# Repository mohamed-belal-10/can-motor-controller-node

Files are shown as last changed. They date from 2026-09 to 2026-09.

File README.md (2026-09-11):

# CAN-Connected Closed-Loop DC Motor Controller Node

A single PCB "smart joint" for robot arms, rovers, or any multi-actuator robotic
system: it bolts onto a DC gearmotor, closes a cascaded current → speed →
position control loop locally on an STM32, and takes setpoints over a shared
CAN bus instead of running dedicated wires back to a central controller.
Multiple nodes share one twisted-pair CAN bus, each addressed independently.

A portfolio project by **Mohamed Belal ("Belo")** — Mechatronics Engineering,
GUC.

---

## Why this project

- **First board with a real power stage.** Current in the amps range, not the
  milliamps of a typical digital-signal board — Kelvin sensing considerations,
  thermal copper, and return-path separation under switching noise.
- **Introduces CAN bus** as a communication protocol, end to end: transceiver
  hardware, bxCAN peripheral configuration, bit-timing, and a companion
  USB-CAN adapter to test it from a laptop.
- **Introduces cascaded multi-loop control** (current → speed → position),
  the conceptual step up from a single-loop PID.
- Built from and cross-checked against two open reference designs: CVRA's
  `motor-control-board` (KiCad, CC-BY) and Cormack's STM32L433 motor driver.

---

## System overview

```
                    ┌──────────────┐      ┌──────────────┐
   12V IN  ────────▶│ LM2596S-5V   │─5V──▶│ AMS1117-3.3  │────▶ 3.3V rail
   (motor            │ buck (switch)│      │ LDO (linear) │      │
    supply)          └──────────────┘      └──────────────┘      │
        │                                                          │
        │ (direct, unregulated)                                    │
        ▼                                                          ▼
   ┌──────────┐    PWM x2      ┌──────────┐   IPROPI    ┌─────────────┐
   │ DRV8874  │◀───────────────│ STM32F103│◀────────────│ (internal to │
   │ H-bridge │                │  C8T6    │             │  DRV8874)    │
   └────┬─────┘                └────┬─────┘             └─────────────┘
        │ motor terminals            │  I²C
        ▼                            ▼
   ┌──────────┐                ┌──────────┐        ┌──────────────┐
   │ DC MOTOR │────coupled────▶│  AS5600  │        │ SN65HVD230   │◀──▶ CAN H/L
   │          │  (shaft end)   │ (angle)  │        │ (transceiver)│    to bus
   └──────────┘                └──────────┘        └──────────────┘
```

Two boards are designed here:

| Board | Role | Location |
|---|---|---|
| **`motor_controller`** | Main node — MCU, power stage, H-bridge, CAN interface | [`hardware/motor_controller/`](hardware/motor_controller/) |
| **`AS5600_Encoder_Node`** | Small sub-PCB carrying the bare AS5600 angle sensor, linked to the main board over a 4-pin JST-SH cable | [`hardware/AS5600_Encoder_Node/`](hardware/AS5600_Encoder_Node/) |

The AS5600 lives on its own tiny PCB — not a generic breakout module —
specifically so the main board's own calculated I²C pull-up resistors are
the *only* pull-ups on the bus (most off-the-shelf breakout modules bundle
their own, which would silently change the bus's effective pull-up value).

---

## Gallery

### Main board — `motor_controller`

<table>
<tr>
<td width="50%">

**PCB layout** (KiCad, top copper + silkscreen)

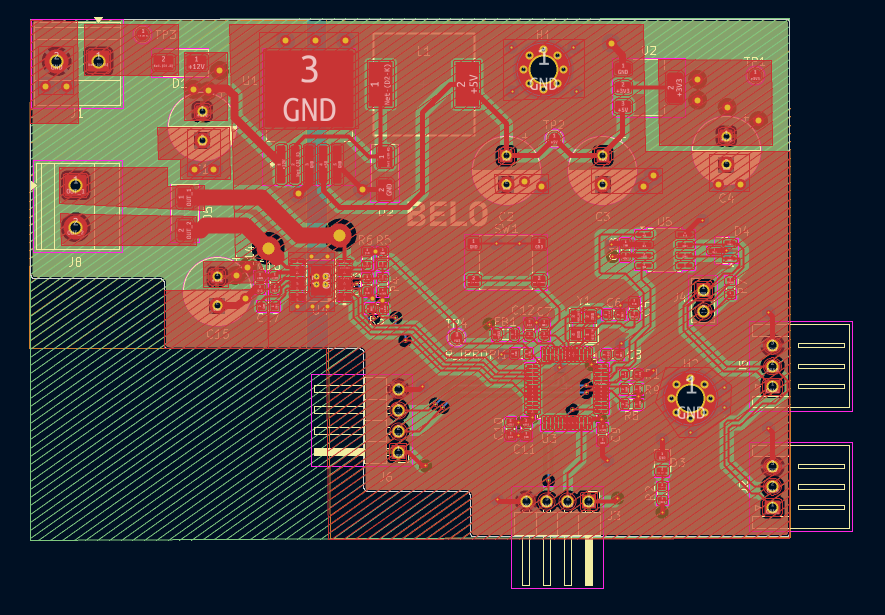
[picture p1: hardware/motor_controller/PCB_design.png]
motor_controller PCB layout


</td>
<td width="50%">

**3D render**

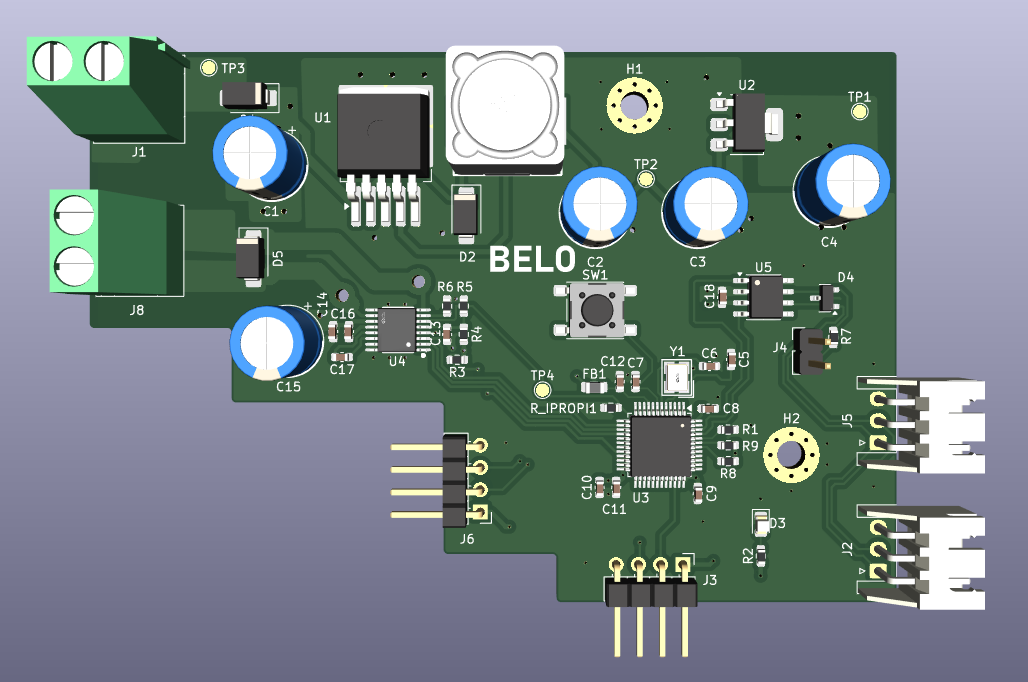
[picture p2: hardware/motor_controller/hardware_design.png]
motor_controller 3D render


</td>
</tr>
</table>

### Sub-board — `AS5600_Encoder_Node`

<table>
<tr>
<td width="50%">

**PCB layout**

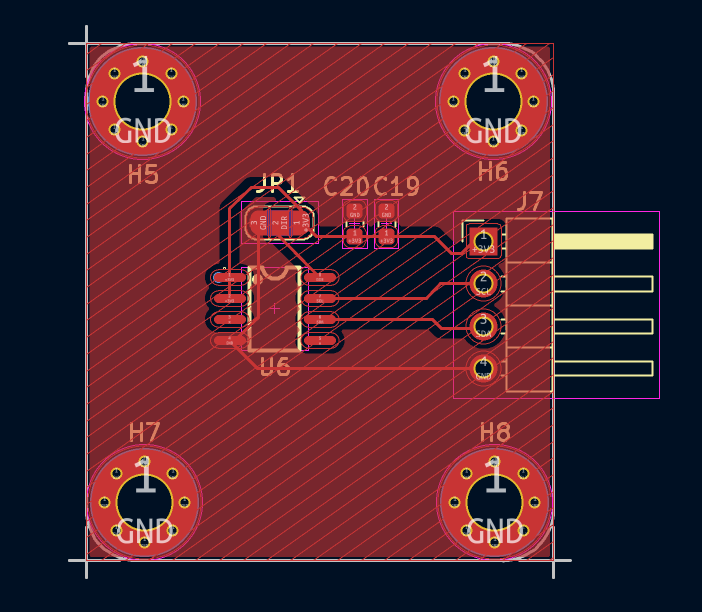
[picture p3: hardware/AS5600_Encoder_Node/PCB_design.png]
AS5600_Encoder_Node PCB layout


</td>
<td width="50%">

**3D render**

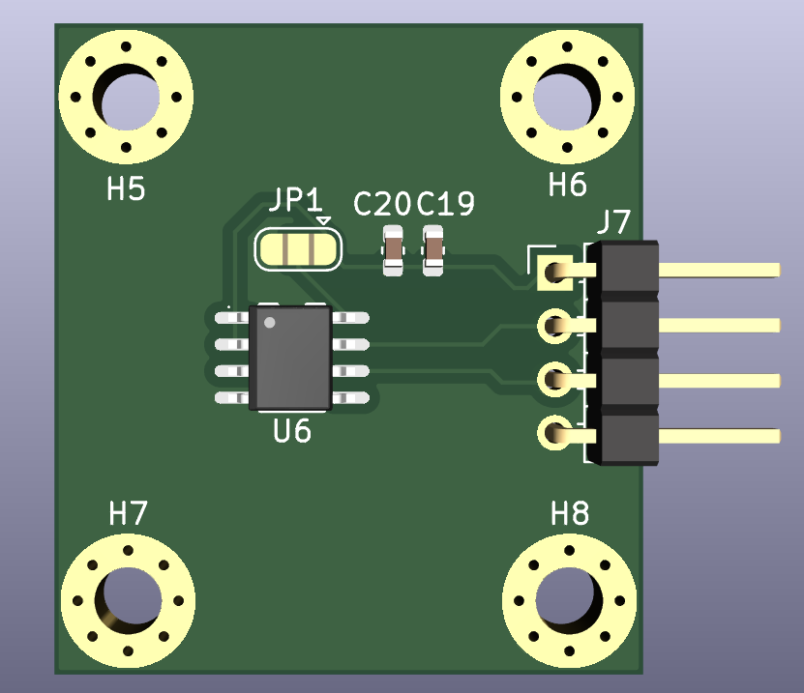
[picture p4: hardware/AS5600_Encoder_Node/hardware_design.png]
AS5600_Encoder_Node 3D render


</td>
</tr>
</table>

---

## Repository structure

```
.
├── README.md
├── LICENSE
├── docs/                                       Design documentation
│   ├── CAN_Motor_Controller_Node_Spec.md           Full BOM, design decisions, CAN protocol, pin map
│   └── CAN_Motor_Controller_Node_PCB_Layout_Guidelines.md   Placement, routing, plane strategy, DRC targets
└── hardware/
    ├── motor_controller/                       Main CAN motor controller node
    │   ├── motor_controller.kicad_pro/.kicad_sch/.kicad_pcb/.kicad_prl
    │   ├── PCB_design.png                          PCB layout screenshot
    │   ├── hardware_design.png                     3D render
    │   └── manufacturing/
    │       ├── gerbers/                            Gerber + drill files
    │       └── motor_controller-gerbers.zip         Fab-ready zip (JLCPCB format)
    └── AS5600_Encoder_Node/                    AS5600 magnetic encoder sub-PCB
        ├── AS5600_Encoder_Node.kicad_pro/.kicad_sch/.kicad_pcb/.kicad_prl
        ├── PCB_design.png                          PCB layout screenshot
        ├── hardware_design.png                     3D render
        └── manufacturing/
            ├── gerbers/
            └── AS5600_Encoder_Node-gerbers.zip
```

All KiCad projects are **KiCad 8+** format.

---

## Main board — `motor_controller`

### Core components

| Subsystem | Part | Notes |
|---|---|---|
| MCU | STM32F103C8T6 (LQFP-48) | 72 MHz, bxCAN, runs all 3 PID loops + CAN stack |
| Clock | 8 MHz HSE crystal, C_L = 20 pF | Required for reliable 500 kbps CAN bit timing (HSI is too loose) |
| Motor driver | DRV8874 (HTSSOP-16, PowerPAD) | Integrated current sense (IPROPI) and cycle-by-cycle current chopping — no external shunt/amplifier needed |
| Power stage | LM2596S-5V (buck) → AMS1117-3.3 (LDO) | Two-stage: switching for efficiency, then linear to give the current-sense ADC a clean reference |
| CAN transceiver | SN65HVD230 (SOIC-8) | 3.3V-only, high-speed mode, `NUP2105L` TVS array for bus ESD protection |
| Encoder | AS5600 (on its own sub-PCB) | 12-bit absolute angle over I²C — see below |
| Actuator | JGA25-370, 12V, 133 RPM, 20 kg·cm | Brushed DC gearmotor, 1:78 gearbox |

### Electrical specs

- **Motor supply:** 12 V nominal (6–18 V DRV8874 range)
- **Current limit:** 2.0 A hardware trip (`I_TRIP`, VREF divider-set), cycle-by-cycle chopping
- **PWM switching frequency:** 20 kHz (H-bridge), 150 kHz (buck)
- **Stackup:** 4-layer — L1 signal, L2 solid GND, L3 split power (VM/3.3V), L4 signal
- **CAN bus:** 500 kbps, standard 11-bit IDs, JST-XH 3-pos daisy-chain connectors (IN/OUT), jumper-selectable 120 Ω termination

### CAN protocol

| Frame | Direction | ID | Payload |
|---|---|---|---|
| Command | host → node | `0x100 + node_id` | `float32` setpoint, `uint8` mode (0=position, 1=speed, 2=current) |
| Telemetry | node → host | `0x200 + node_id` | `float32` position, `uint16` current (mA), `uint8` fault flags |

`node_id` is assigned in firmware at flash time — no address jumpers on the
board.

### Design status

- ✅ All five schematic sheets complete (Power Stage, MCU Core, Motor Drive,
  CAN Bus, Sensing), ERC clean.
- ✅ Every component value and part number closed, across four audit passes
  (full history in [`docs/CAN_Motor_Controller_Node_Spec.md`](docs/CAN_Motor_Controller_Node_Spec.md)).
- ✅ Layout complete; gerbers generated (see `manufacturing/`).
- ⚠️ **Flagged, unresolved:** DRV8874 power-up sequencing (VCC vs. VM order)
  not verified against the datasheet.
- ⚠️ **Open before re-ordering:** cross-check the main board's AS5600 link
  connector pin order against the sub-PCB's `J1`/`J7` connector — both
  footprints were placed independently.
- 🚚 **Externally sourced, not yet in hand:** DRV8874 (not stocked locally —
  ordered internationally), diametrically-magnetized magnet (must confirm
  magnetization type with seller before buying).

---

## Sub-board — `AS5600_Encoder_Node`

A minimal breakout for the bare AS5600 magnetic rotary position sensor
(SOP-8), designed specifically to avoid the double-pull-up problem that
off-the-shelf AS5600 modules introduce.

| Item | Detail |
|---|---|
| Sensor | AS5600 (SOP-8), 12-bit absolute angle over I²C |
| Power wiring | `VDD5V` and `VDD3V3` tied together, fed from the main board's 3.3V rail (required for correct 3.3V single-supply operation per datasheet) |
| Decoupling | 100 nF + 10 µF in parallel across the tied VDD node → GND (matches datasheet Fig. 13, 3.3V-mode) |
| Direction select | 3-pad solder jumper (`DIR`: GND = CW-increasing, VDD = CCW-increasing) — bridged at assembly time once motor orientation is known |
| Link to main board | JST-SH, 1.0 mm pitch, 4-position — carries `+3V3`, `SCL`, `SDA`, `GND` |
| Mounting | Glued flat to the motor's rear shaft-stub end face, read through a 1.0–1.5 mm air gap by a 6 mm diametric NdFeB magnet |
| Encoder resolution | 4096 counts/rev at the motor shaft → 319,488 counts/rev at the JGA25-370's output shaft (through its 1:78 gearbox) |

The AS5600 mounting bracket (clamp-style, sized to the motor's 25 mm body OD)
is specified mechanically in [`docs/CAN_Motor_Controller_Node_Spec.md`](docs/CAN_Motor_Controller_Node_Spec.md#9-as5600-mounting-bracket-mechanical-spec--solidworks-task)
but deliberately not finalized until the physical sub-PCB and motor are in
hand to confirm dimensions.

---

## Documentation

| Document | Covers |
|---|---|
| [`docs/CAN_Motor_Controller_Node_Spec.md`](docs/CAN_Motor_Controller_Node_Spec.md) | Full BOM with sourcing/pricing notes, design-decision rationale, CAN protocol definition, STM32 pin assignment tracker, CAN-adapter companion tool, AS5600 mounting bracket spec |
| [`docs/CAN_Motor_Controller_Node_PCB_Layout_Guidelines.md`](docs/CAN_Motor_Controller_Node_PCB_Layout_Guidelines.md) | Trace sizing, via strategy, floorplan, placement rules, ground/power plane strategy, CAN routing, thermal, DRC targets, pre-routing checklist |

---

## Build sequence

1. Schematic capture (CAN node + power stage + DRV8874 + AS5600) — **done**
2. ERC clean — **done**
3. Layout — **done**
4. DRC clean, JLCPCB stackup check, order
5. Bring-up: power rails → CAN enumeration → AS5600 sanity read → close current loop → speed loop → position loop
6. Bring up the companion CAN-USB adapter and drive the node from a laptop with real command/telemetry frames

Full detail on each step, including the CAN-USB adapter's own BOM, wiring,
and firmware plan, is in [`docs/CAN_Motor_Controller_Node_Spec.md`](docs/CAN_Motor_Controller_Node_Spec.md#7-build-sequence).

---

## Fabrication

Both boards are designed for JLCPCB (4-layer main board, 2-layer sub-PCB).
Ready-to-upload gerber/drill packages are checked in under each board's
`manufacturing/` folder. Re-export from KiCad's Plot dialog after any layout
change rather than editing the checked-in gerbers by hand.

## Reference designs

- [CVRA `motor-control-board`](https://github.com/cvra) — KiCad, CC-BY, near-identical spec; source for the CAN daisy-chain connector and termination-jumper approach.
- Cormack's STM32L433 motor driver — single-board layout reasoning, undervoltage-lockout-as-safety-feature technique.

## License

MIT — see [`LICENSE`](LICENSE).

This repository contains PCB hardware design files (KiCad schematics,
layouts, and manufacturing outputs) alongside documentation. The MIT License
is applied for simplicity and consistency with the author's other portfolio
repositories; no warranty is made or implied about the fitness of any
hardware design herein for use with live mains, high-current, or
safety-critical applications. Build and operate at your own risk.

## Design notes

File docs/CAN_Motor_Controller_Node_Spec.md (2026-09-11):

# CAN-Connected Closed-Loop DC Motor Controller Node

**A portfolio project for Mohamed Belal ("Belo") — Mechatronics Engineering, GUC**
**Status:** **Every electrical design decision and component value closed**, across four audit passes. **Schematic capture in progress in KiCad — all five subsystem sheets drawn (Power Stage, MCU Core, Motor Drive, CAN Bus, Sensing).** **One item flagged but deliberately unresolved:** DRV8874 power-up sequencing (VCC vs. VM order) — check during schematic capture. **Three items remain deliberately deferred:** DRV8874 sourcing, magnet sourcing (both external, your action), and the AS5600 bracket finalization (§9, paused until the sub-PCB layout exists). **One item open before ERC/layout:** cross-check that the main board's AS5600 link connector and the sub-PCB's `J1` connector share the same pin order (§3.4) — both were placed independently.
**Prerequisite:** ESP-Drone board ordered and fabricated first

---

## 1. Project Description

This is a single PCB — one "smart joint" of the kind used in robot arms, rovers, or any multi-actuator robotic system. It bolts onto a DC motor, closes a cascaded position/speed/current control loop locally, and takes setpoints over a CAN bus instead of running dedicated wires back to a central controller. Two or more of these boards can share one twisted-pair CAN bus, each addressed independently.

**What it does, end to end:**
1. A command arrives over CAN — *"go to position X"* or *"hold speed Y."*
2. The onboard STM32 runs three nested PID loops (current → speed → position) to get the motor there safely and smoothly.
3. The board reports back over CAN: current position, speed, motor current, fault flags.

**Why this project, specifically:**
- It's the first board with a **real power stage** — current in the amps range, not the milliamps of ESP-Drone's digital signals. This is the actual PCB skill gap in your record: Kelvin sensing, thermal copper, return-path separation under switching noise.
- It introduces **CAN bus**, currently a zero on your skill matrix and the exact protocol your DLR-thesis framing is built around.
- It introduces **cascaded multi-loop control**, the conceptual bridge between the single-loop PID you already proved on maglev and the state-space work further down your priority list.
- It's a legitimate, honest answer to "tell me about your robotics work" — an actuator control node, not an inflated claim.

**Reference designs this is built from:** CVRA's `motor-control-board` (KiCad, CC-BY, near-identical spec) and Cormack's STM32L433 motor driver (single-board layout reasoning, undervoltage-lockout-as-safety-feature trick). Read both `.kicad_pcb` files directly before drawing your own schematic, the way you did with ESP-Drone.

---

## 2. System Architecture

```
                    ┌──────────────┐      ┌──────────────┐
   12V IN  ────────▶│ LM2596S-5V   │─5V──▶│ AMS1117-3.3  │────▶ 3.3V rail
   (motor            │ buck (switch)│      │ LDO (linear) │      │
    supply)          └──────────────┘      └──────────────┘      │
        │                                                          │
        │ (direct, unregulated)                                    │
        ▼                                                          ▼
   ┌──────────┐    PWM x2      ┌──────────┐   IPROPI    ┌─────────────┐
   │ DRV8874  │◀───────────────│ STM32F103│◀────────────│ (internal to │
   │ H-bridge │                │  C8T6    │             │  DRV8874)    │
   └────┬─────┘                └────┬─────┘             └─────────────┘
        │ motor terminals            │  I²C
        ▼                            ▼
   ┌──────────┐                ┌──────────┐        ┌──────────────┐
   │ DC MOTOR │────coupled────▶│  AS5600  │        │ SN65HVD230   │◀──▶ CAN H/L
   │          │  (shaft end)   │ (angle)  │        │ (transceiver)│    to bus
   └──────────┘                └──────────┘        └──────────────┘
```

---

## 3. Final Component List

### 3.1 Core compute & communication

| Component | Role | Key specs | Package | Local availability |
|---|---|---|---|---|
| **STM32F103C8T6** | Main MCU. Runs all three PID loops, reads the encoder over I²C, drives PWM to the H-bridge, runs the CAN peripheral (bxCAN). | 72 MHz, bxCAN built in, 5V-tolerant GPIO on most pins | LQFP-48 | ✅ Local (Future Electronics Egypt / UGE) |
| **8MHz crystal (HSE) + load caps** | External oscillator for the STM32 — feeds the internal PLL to reach the full 72MHz core clock. **Required for reliable CAN bit timing** at 500kbps; the internal RC oscillator (HSI) has looser tolerance and drift that isn't recommended for CAN. This is genuinely new territory for this board — previous boards (maglev) used the Blue Pill module, which has this circuit built in; this board uses the bare LQFP-48 chip, so the oscillator circuit has to be designed here for the first time. **Sourced: 3225 SMD quartz 4-pin crystal, 8MHz, `C_L=20pF` (UGE Electronics Egypt).** Load caps: **C1=C2=20pF**, matched directly to the crystal's own specified load capacitance. No external feedback resistor needed — internal to the STM32. Connects to the dedicated `OSC_IN`/`OSC_OUT` pins, not the general GPIO pool. | 8MHz, C_L=20pF, ±10ppm tolerance | 3225-SMD (crystal) + 0402/0603 (caps) | ✅ Local (UGE Electronics Egypt) |
| **Reset circuit (`NRST`)** | Manual/clean reset for the STM32. **No external pull-up needed** — the chip has one built in (~40kΩ, per datasheet). Add a **100nF capacitor** `NRST`→GND to filter noise and stretch the reset pulse on power-up, plus a **momentary push-button** `NRST`→GND for manual reset during bring-up/debugging without power-cycling the board. | 100nF cap + momentary pushbutton | Passive + button | ✅ Local, trivially common parts |
| **`BOOT0` strapping** | Selects boot source: low=main flash, high=system bootloader. **Tied to GND via a fixed 10kΩ pull-down** — no jumper. Since programming is exclusively via ST-Link/SWD (same as ESP-Drone and maglev), the system bootloader is never needed, so a fixed tie-down is simpler and more reliable than a selectable jumper. | 10 kΩ | Passive, 0603/0805 | ✅ Local |
| **STM32 decoupling capacitors** | Standard MCU support that was missing from the BOM entirely. **Precise breakdown for this LQFP-48 package: 3 digital `VDD` pins → 3× 100nF ceramic (one per pin, placed as close to each pin as layout allows), plus 1× 4.7µF bulk cap on the `VDD` rail. Separately, `VDDA`/`VSSA` (the analog supply feeding the ADC) gets its own 100nF, ideally isolated from digital `VDD` by a small series ferrite bead.** `VBAT` ties directly to `VDD` (no RTC backup battery in this design). This isn't a generic nice-to-have on this board specifically: `VDDA` is the literal reference voltage the ADC measures `IPROPI` against, so noise leaking onto it from the digital rail *is* current-measurement error, not just abstract EMC hygiene — it connects directly to the entire reason this board has a two-stage `LM2596→AMS1117` power architecture in the first place. All of these caps benefit from via-ing straight down to the solid ground plane (L2 of the 4-layer stackup already decided) right under each pad. | 3× 100nF (digital VDD) + 1× 4.7µF bulk + 1× 100nF (VDDA) + ferrite bead | Passive | ✅ Local |
| **Power-on LED + resistor** | Genuinely missing until this audit: no visual "is this board alive" indicator existed anywhere. Placed on the 3.3V rail — the first, cheapest signal you get the moment power is applied, before any probe or debugger is connected. Standard practice, especially valuable across the multi-stage bring-up sequence in §7. | Standard LED + series resistor sized for ~2-5mA at 3.3V (e.g. 1kΩ for a typical red LED) | Passive + LED | ✅ Local |
| **SN65HVD230** | CAN transceiver. Converts the MCU's digital CAN TX/RX signals into the differential CAN-H/CAN-L signaling that travels on the bus, and back. Standard **100nF local decoupling cap** at the VCC pin (not previously listed). **`RS` (pin 8) tied directly to GND** — selects high-speed mode (datasheet: strong pull-down to GND = high-speed, no slew-rate limiting). Standby/sleep mode is never used on this board, so a fixed tie-down is correct rather than routing RS to a GPIO. **`Vref` (pin 5) left floating (N/C)** — only meaningful with split termination (tying to the split's center point); this board uses standard single-resistor termination, and the datasheet explicitly permits leaving Vref floating when unused. | **3.3V supply only** — do not power from 5V | SOIC-8 | ✅ Local (UGE Electronics Egypt) |
| **120 Ω termination resistor** | Placed across CAN-H/CAN-L at each physical end of the bus cable, jumper-selectable. Prevents signal reflections that corrupt CAN frames. **Decided: 2-pin, 2.54mm pin header + removable jumper shunt cap**, in series with the resistor. Cap installed = termination enabled; cap removed = disabled. Chosen over a solder jumper specifically because the board's dual JST-XH IN/OUT connectors are designed for future daisy-chaining — if a third node is ever added mid-chain, this board's termination may need to be toggled off without breaking out a soldering iron. Matches how CVRA's reference board (this project's basis) handles it. | Standard 0805/1206 resistor + 2-pin 2.54mm header + shunt cap | Passive | ✅ Local (generic passive, any store) |

### 3.2 Power stage & motor drive

| Component | Role | Key specs | Package | Local availability |
|---|---|---|---|---|
| **DRV8874** | H-bridge motor driver. Takes PWM logic signals from the MCU and switches full motor current (volts/amps) to the motor. **Has a built-in current-sense pin (IPROPI)** — outputs a current proportional to actual motor current, set by one external resistor (`R_IPROPI`). No separate shunt resistor or current-sense amplifier IC needed. **Two layout requirements not previously noted:** standard **100nF local decoupling** at the `VCC` (logic supply) pin; and the HTSSOP-16 package's **exposed thermal pad needs via-stitching to a copper pour** for heat dissipation, genuinely relevant here given the current-limiting events this board is designed to handle regularly (`I_TRIP` chopping during stalls). | Up to ~6.5 A continuous, 4.5–37 V motor supply, integrated current sense, integrated current regulation/chopping | HTSSOP-16 (PowerPAD) | ❌ **Not stocked locally.** You've confirmed you'll source it internationally regardless (Digikey/Mouser/RS/TME, or a Pololu carrier board as an import fallback). Lead time and shipping cost apply — order early. |
| **R_IPROPI** | Sets the current-sense gain (converts DRV8874's IPROPI output current into a readable voltage for the ADC). **Calculated: 2.2 kΩ** — sized so the STM32's 3.3V ADC reads full-scale at ~3.3A (headroom above the JGA25-370's 1.2A stall current), giving stall current a clean ~36% of ADC range. `A_IPROPI` = 455 µA/A per DRV8874 datasheet. Output routes to **`PA0` (ADC1_IN0)** — see §5.2 pin tracker. | 2.2 kΩ, precision resistor recommended (1% tolerance) | Passive, 0603/0805 | ✅ Local |
| **VREF divider** | Sets the DRV8874's hardware current-chopping trip point (`I_TRIP`), independent of firmware — a physical safety backstop. **Calculated: R1 = 3.3 kΩ (3.3V→node), R2 = 5.1 kΩ (node→GND)**, giving `VREF = 2.004V` → `I_TRIP ≈ 2.0A`. Add a **100nF filter cap** from the VREF node to ground — the divider alone will pick up H-bridge switching noise, and since VREF sets a hard trip threshold, that noise can cause false trips. | R1 = 3.3kΩ, R2 = 5.1kΩ, C = 100nF | Passive | ✅ Local |
| **LM2596S-5V** | Buck converter, bare IC, fixed 5V output. Steps 12V motor supply down to a regulated 5V intermediate rail. **This is your one real switching-regulator layout exercise** — inductor selection, switching-node layout, feedback network — with no output-voltage calculation needed since it's a fixed-voltage part. | 3A continuous, 150 kHz switching, TO-263 | TO-263 (SMD) | ✅ Local (UGE Electronics Egypt) |
| **AMS1117-3.3** | Linear regulator (LDO), fixed 3.3V output. Takes the 5V rail down to the clean 3.3V logic rail powering the STM32, SN65HVD230, and AS5600. Chosen specifically to sit *after* the switcher: an LDO rejects the switching noise the LM2596 leaves on its output, giving the MCU's ADC a cleaner reference — which matters because the ADC is also reading the DRV8874's IPROPI current-sense signal. Noise on the supply becomes noise in the current measurement. **Output cap: 22µF electrolytic, 25V rating** — confirmed sourced (Flux Electronix Egypt, 0.75 EGP). Electrolytic works as well as tantalum here: its higher ESR naturally sits within the AMS1117's required 0.3–22Ω stability window, the opposite problem ceramic has. **Note: through-hole part** — since the board's assembly plan is JLCPCB SMT, this one component will likely need hand-soldering after assembly rather than going through the automated run, unless swapped for an SMD electrolytic. **Input cap: 10µF tantalum/electrolytic.** | 1A output, dropout ~1.1V, fixed 3.3V | SOT-223 | ✅ Local / near-universal — stocked everywhere, including as a standalone part at UGE |
| **Inductor** (buck stage) | Energy-storage element for the switching regulator. | **68 µH — confirmed part: `CD54-680M` (DMBJ / Dongguan Zhenbaojia Electronics), 6.1×5.5×4.85mm, in stock at 11.50 EGP. Datasheet-confirmed: DCR max 0.46Ω, IDC max 0.61A** (defined as the current causing either 25% inductance drop or 40°C temperature rise, whichever is smaller — a thermally-soft limit, not a hard cliff edge). Checked against this rail's realistic load: STM32 (~35–50mA active) + SN65HVD230 (~10–70mA) + AS5600 (a few mA) totals roughly 100–150mA steady-state, giving **~4–6× headroom** under the 0.61A rating — comfortable margin including power-up inrush. DCR loss at this current is trivial (~10mW). **No further verification needed — this is a fully specified, sourced, in-stock part.** | SMD power inductor | ✅ Local, confirmed in stock, datasheet-verified |
| **Schottky catch diode** (buck stage) | Provides the current path when the LM2596's internal switch is off. | 3A, low forward-voltage Schottky (e.g. SS34-class) | SMA/DO-214 | ✅ Local (generic, widely stocked) |
| **Reverse-polarity protection diode** | Series diode in the +12V input line, before it splits to DRV8874 `VM` and the `LM2596S-5V` input. Blocks all current if the supply is ever connected backward — a real bench mistake this protects against, cheaply. **Reuses the same 3A SS34-class Schottky already specified for the buck stage's catch diode** — one fewer distinct BOM part rather than sourcing a second diode type. Forward drop (~0.4V) is inconsequential here: the motor tolerates 6–18V and the buck stage has ample input headroom either way. Power dissipation at `I_TRIP` (2A): ~0.8W momentarily during a stall — well within the diode's 3A rating with real margin. A P-channel MOSFET "ideal diode" would lose less voltage/power, but adds gate-biasing complexity not worth it at these current levels for a first board. | Same part as buck catch diode — 3A SS34-class Schottky | SMA/DO-214 | ✅ Local (same sourcing as buck diode) |
| **`nFAULT` pull-up resistor** | Required for the DRV8874's open-drain `nFAULT` output to read as a valid logic high when no fault is present. | 10 kΩ | Passive, 0603/0805 | ✅ Local |
| **VM bulk capacitor + local decoupling** | Absorbs energy kicked back from the motor winding's inductance during switching/current-limit events, preventing voltage sag/spikes on the 12V rail that would otherwise show up as noise in the current-sense reading. **Sized via energy estimate: `E=½LI²` at I_TRIP=2.0A with an assumed ~2mH motor winding inductance (not datasheet-confirmed — this motor doesn't publish it) gives ~264µF for a 10% rail-voltage-rise tolerance.** Rounded to a standard value: **220–330µF electrolytic, 25V rated**, placed close to the DRV8874's VM pin, plus a **0.1–1µF ceramic** alongside it for the fast edges the electrolytic can't respond to in time. | 220–330µF/25V electrolytic + 0.1–1µF ceramic | Mixed | ✅ Local (basic, common values — same store tier as the AMS1117 cap) |
| **Bulk/decoupling capacitors** | Input/output filtering for the buck stage, input/output caps for the LDO (per AMS1117 datasheet — it needs a minimum output cap for stability), plus local decoupling at every IC's supply pin. | Electrolytic (bulk) + ceramic (decoupling), values per datasheet | Mixed | ✅ Local |

### 3.3 Sensing

| Component | Role | Key specs | Package | Local availability |
|---|---|---|---|---|
| **AS5600** | Magnetic rotary position sensor. Reads a small diametric magnet mounted on the motor shaft end and reports absolute shaft angle over I²C. Chosen over a mechanical 600 PPR encoder because it's **absolute** (always knows true position immediately, even after a reset or glitch) rather than incremental (loses position on any missed pulse or power interruption). **Implementation decided: bare SOP-8 IC on its own small dedicated sub-PCB (not a generic breakout module).** Most off-the-shelf breakout modules include their own onboard I²C pull-ups — combined with the main board's already-calculated 4.7kΩ pull-ups, the parallel result (~2.35kΩ) would quietly undo that calculation. Bare IC + own sub-PCB keeps the main board's pull-ups as the only ones on the bus, and matches how CVRA/Cormack's reference boards do it. Connects to the main board via a **JST-SH 1.0mm 4-position connector** (see §3.4 for the part) rather than a vague loose cable. Consider panelizing this small sub-PCB alongside the main board in the same JLCPCB order. **Power pin wiring — real datasheet requirement, previously missed: for 3.3V single-supply operation (this board's case), `VDD5V` and `VDD3V3` pins must be tied together and both fed from the 3.3V rail directly.** Getting this wrong (leaving `VDD3V3` floating, or not tying the two pins) is a real, easy schematic mistake for this specific chip. **Decoupling — corrected during schematic capture: `C1 = 100nF` + `C2 = 10µF`, both in parallel across the tied `VDD5V`/`VDD3V3` node to `GND`.** This matches the datasheet's own 3.3V-operation diagram (Fig. 13) exactly, not the separate 5V-mode "1µF LDO cap" table (Fig. 39) that doesn't apply once the internal LDO is bypassed by tying the two supply pins together. The 10µF value is specifically required for OTP burn procedures at 3.3V — kept in the design even though OTP burning isn't planned, since it's a negligible cost to leave in and guarantees the option stays open. **Bare IC confirmed local at UGE Electronics Egypt — but listed at 7,700 EGP, dramatically higher than typical pricing for this chip (a few dollars via LCSC).** Worth confirming actual unit quantity/price directly with UGE before ordering — this may be a bulk-reel listing or pricing error rather than a genuine per-unit cost. Your established LCSC + `easyeda2kicad` pipeline is very likely the cheaper route for this specific part even with international shipping. | 12-bit (4096 counts/rev), I²C interface, 3.3–5V supply | SOP-8 (bare IC, on its own sub-PCB) | ⚠️ Confirmed local but price unverified — compare against LCSC before committing |
| **Diametric magnet** | Mounted flush on the motor shaft end, read by the AS5600 through the PCB. **Mounting method decided: glued flat onto the shaft stub's end face**, centered on the rotation axis — not fitted around the shaft diameter via a collar. This sidesteps a real gap: the JGA25-370's rear shaft stub dimensions aren't published anywhere (checked the manufacturer manual and multiple listings — only the front output shaft is dimensioned). Gluing flat only requires the shaft end to be reasonably flat and accessible, true for essentially any small DC motor, and doesn't depend on knowing the shaft diameter at all. | 6mm diameter × 2.5mm–3mm thick, diametrically magnetized, N35–N42 grade | — | ❌ **Not confirmed local.** A cheap local candidate (Electra Store-style CNC/3D-printer supplier, 6×3mm, 8 EGP) was found, but the listing only says "neodymium disc magnet" — doesn't state diametric vs. axial magnetization, and the product photo shows the magnets stacking flat-face-to-flat-face, the classic behavior of **axial** magnets (poles on the flat faces). Diametric magnets (poles split across the round edge) don't stack that way. Axial magnets will not work with the AS5600 — they don't produce the rotating field the sensor needs. **Must confirm "diametrically magnetized" explicitly with the seller before buying**, or default to a specialty supplier / AliExpress listing that states it outright. |
| **I²C pull-up resistors** | Required on SDA/SCL lines for any I²C bus to function — open-drain signaling needs external pull-ups. **Calculated: 4.7kΩ, confirmed against the I²C-bus spec formula, not just assumed.** With `V_DD=3.3V`, `I_OL(max)=3mA`: `Rp(min) = (3.3−0.4)/0.003 ≈ 966Ω`. With an estimated bus capacitance of ~50pF (short on-board trace, two devices) at Standard-mode 100kHz (plenty fast — the AS5600 is only read once per ~10ms position-loop tick): `Rp(max) = 1000ns/(0.8473×50pF) ≈ 23.6kΩ`. **4.7kΩ sits comfortably mid-range** between 966Ω and 23.6kΩ — well-margined on both rise time and static current, not just a default that happens to work. Both resistors pull to **3.3V** (matching AS5600/STM32 logic level, not 5V). Placed only on the main board — deliberately **not** duplicated on the AS5600 sub-PCB, to avoid a second parallel pull-up quietly shifting the calculated value. | 4.7 kΩ ×2 | Passive | ✅ Local |
| **`JP1` — DIR configuration jumper** | Sets the AS5600's counting direction (`DIR` pin: GND = clockwise-increasing, VDD = counterclockwise-increasing). **Decided during schematic capture: 3-pad SMD solder jumper**, not a fixed tie. Center pad → `DIR`, one outer pad → `+3V3`, other outer pad → `GND`. Defers the CW/CCW decision from schematic time to assembly time — bridge whichever side matches the physical mounting once the motor and bracket are in hand, rather than guessing polarity now and risking a respin. | 3-pad solder jumper | Passive | ✅ Local (generic) |
| **AS5600 `OUT`/`PGO` pins** | **`OUT` (Pin 3): No-Connect.** Angle is read digitally over I²C (`ANGLE` register); the analog/PWM output isn't used. **`PGO` (Pin 5): No-Connect**, relying on its internal pull-up. Programming is done via I²C (datasheet Option A), so the OUT-pin programming path (Option B, which requires `PGO` tied to GND) doesn't apply. | — | — | — |

### 3.4 Connectors

| Component | Role |
|---|---|
| **SWD header (4-pin)** | Programming/debugging the STM32 via ST-Link. |
| **Power input connector** | Brings in 12V (or your chosen motor supply voltage). **Decided: 2-pin, 5.08mm pitch screw terminal block** (UGE Electronics Egypt or Micro Ohm's pluggable M+F version, ~6 EGP). Rated 10–16A depending on exact manufacturer — real-world worst-case current here is ~2.1–2.2A (motor's I_TRIP-limited draw plus buck stage overhead), giving **~5–7× headroom**, not a tight fit. Same part reused for the motor output connector below — one fewer distinct BOM entry. |
| **CAN bus connector** | **Decided: JST-XH, 2.5mm pitch, 3-position (CAN-H, CAN-L, GND). Two identical connectors per board ("IN" and "OUT"), both wired to the same three nets internally**, enabling clean node-to-node daisy-chaining rather than star wiring or splicing. Only the two physical end-of-bus boards need their `120Ω` termination jumper enabled. GND included (not just the two CAN signal lines) since each board has its own independent power supply — there's no other shared ground reference between nodes otherwise. Standard, locking, polarized, widely available. **ESD protection: `NUP2105L` dual-channel TVS diode array, placed at the connector before the `SN65HVD230`.** Industry-standard part built specifically for CAN bus protection — IEC 61000-4-2 ESD rated to 30kV, automotive-grade (AEC-Q101), SOT-23 package, low enough capacitance (30pF) to not distort CAN signal integrity. **Confirmed local: UGE Electronics Egypt.** Warranted here specifically because this connector is externally exposed — cables plugged/unplugged between boards. |
| **Motor output connector** | **Decided: same 2-pin, 5.08mm pitch screw terminal block as the power input connector** — reused part, not a separate one. Motor current is hard-capped at `I_TRIP` (2.0A) by the DRV8874's hardware chopping, never higher in sustained operation — well within the connector's 10–16A rating. Easy to service for a first board (loosen/tighten screws, or unplug entirely if using the pluggable variant). **ESD/transient protection: generic bidirectional TVS diode across the motor terminals**, rated above the 12V rail. Lower priority than the CAN connector — the DRV8874 already handles switching-induced transients internally and the VM bulk cap already absorbs winding energy — but this connector is still externally touchable, so a basic external-event backstop is worth the trivial part cost. |
| **AS5600 sub-PCB link connector** | Connects the small AS5600 sub-PCB (§3.3) to the main board — carries VCC/GND/SDA/SCL. **Decided: JST-SH, 1.0mm pitch, 4-position**, on both the main board and sub-PCB sides. Standard, small, low-profile connector for exactly this kind of low-pin-count sub-board link. Closes an earlier vagueness — previously just described as "a short 4-wire cable" with no actual connector specified. **Pinout, sub-PCB side (`J1`): Pin 1 = `+3V3`, Pin 2 = `I2C1_SCL`, Pin 3 = `I2C1_SDA`, Pin 4 = `GND`.** ⚠️ **Not yet cross-checked against the main board's matching connector** — JST-SH is keyed against reversal, but not against a pin-order mismatch between two independently-placed footprints. Verify both sides agree pin-for-pin before ordering. **Harness guidance:** keep this cable short and, if using discrete wires rather than a ribbon, pair SDA and SCL each with an adjacent GND (or lightly twist) — this cable runs near the DRV8874/motor switching noise this board's EMC audit (§10) was written around, and I²C has no error correction to fall back on if a transaction glitches. |
| **Main PCB mounting holes** | Genuinely missing until this audit — nothing addressed how this board physically attaches to anything (a chassis, fixture, or eventual robot mount). **Decided: 4× M3 mounting holes**, one near each corner, with standard clearance from components and copper per JLCPCB's keep-out rules. |
| **Test points** | Not previously included. Exposed pads/points for **3.3V, 5V, VM, and the `IPROPI` voltage** — cheap, easy to add during layout, and directly useful across the multi-stage bring-up sequence in §7 (probing rail health and the current-sense signal without hunting for a component leg). |

### 3.5 Motor

| Component | Role | Key specs | Local availability |
|---|---|---|---|
| **JGA25-370, 12V, 133 RPM, 20 kg·cm** | The actuator this board drives. Brushed DC gearmotor with an accessible rear shaft stub (before the gearbox) for AS5600 magnet mounting. | 12V nominal (6–18V range), 1:78 metal gearbox, 4mm D-shaft output, free-run current 50 mA, **stall current 1.2 A** | ✅ Local (Electra Store, Egypt — 360 EGP, currently on backorder) |

## 4. Design Notes Worth Remembering

**Why DRV8874 changes the BOM from earlier drafts.** Earlier planning assumed a DRV8871 substitute (locally available, but lacking integrated current sense), which required adding an external shunt resistor plus an INA240-family current-sense amplifier. Since you're proceeding with the real DRV8874, **that external current-sense stage is no longer needed** — the DRV8874's IPROPI pin does the job internally. This simplifies the board: one fewer IC, one fewer Kelvin-sensing layout problem. (You still get real power-stage layout experience from the buck converter and the motor-current traces themselves, so the core learning goal is intact.)

**Why there's no separate 5V rail anymore.** ~~The AS5600 (unlike the mechanical encoder originally considered) runs happily on 3.3V. Nothing else on this board needs 5V.~~ **Superseded — the 5V rail is back, but now as an intentional intermediate stage rather than an end rail.** Nothing on the board *needs* 5V directly (STM32 and SN65HVD230 are 3.3V-only; AS5600 is fine at 3.3V), but the power architecture is now two stages: `LM2596S-5V` (switching, noisy but efficient) feeding `AMS1117-3.3` (linear, clean but lossy). This trades a small amount of efficiency (the LDO burns the 5V→3.3V difference as heat, which is negligible at this current draw) for a materially quieter 3.3V rail — worth it specifically because that rail also feeds the ADC reading motor current. It also removes the feedback-resistor-divider calculation that the single-stage `LM2596S-ADJ` approach required, since both `LM2596S-5V` and `AMS1117-3.3` are fixed-voltage parts.

**Voltage safety check, already applied to this BOM:**
- STM32 and SN65HVD230 → 3.3V only, strictly.
- DRV8874 has two separate supply inputs — VM (motor voltage, e.g. 12V) and VCC (logic supply, 3.3–5V) — don't cross them.
- AS5600 → 3.3–5V, flexible.

**Encoder resolution, through the gearbox.** The AS5600 gives 4096 counts/rev at the motor's fast shaft. Through the JGA25-370's 1:78 gear ratio, that's `4096 × 78 = 319,488` counts per revolution of the actual output shaft — about 0.0011° per count. Resolution is not a limiting factor for this build; mechanical backlash in the gearbox will dominate positioning accuracy long before encoder resolution does.

**How cycle-by-cycle current limiting actually behaves.** When motor current crosses `I_TRIP` (2.0A) mid-PWM-cycle, the DRV8874 doesn't wait for the cycle to end — after a short blanking + deglitch delay (tens to hundreds of nanoseconds, rejects switching noise rather than reacting to it), it chops the output off for whatever remains of that period, then tries again at the next period boundary. Current decays through the motor's normal freewheeling path during that off-time — nothing is "held" at a fixed value, it's the same inductor decay physics as a normal PWM off-time, just triggered early.

The off-duration is **not constant** — it depends on duty cycle. At 20kHz (`T = 50µs`), if the trip happens right after blanking ends, the off-duration is close to a full period (~50µs) regardless of duty cycle. But the *shortest possible* off-duration shrinks as duty cycle rises — at 90% duty cycle the floor is only ~5µs, at 30% duty cycle it's ~35µs — because that floor is just the duty cycle's normal off-time (`(1−D) × T`). Since the PID loop changes `D` every cycle, this floor moves around continuously during operation. Practical effect: average current during a sustained stall isn't perfectly flat — it has some cycle-to-cycle wobble tied to duty cycle, visible as a slightly uneven (though still safely bounded) shape if you ever plot `IPROPI` during a stall event. This was weighed against fixed off-time (a constant off-duration set by an external timer, giving a flatter stall-current profile) and cycle-by-cycle was kept anyway, because fixed off-time introduces a second hardware timer that can briefly override firmware PWM commands during a stall — added complexity not worth it for a general-purpose gear motor that isn't delicate.

Two safety layers exist independently: your 2.0A `I_TRIP` (tuned to this motor's real operating range, described above) and the DRV8874's own separate, much higher hardware overcurrent protection (OCP) that protects the chip itself against events like a dead short — not user-configured, always active regardless of `I_TRIP`/`IMODE` settings.

**DRV8874 sourcing.** Since it's not stocked in Egypt, budget for international shipping lead time (Digikey/Mouser/RS/TME direct, or a pre-assembled Pololu carrier board as a fallback that trades layout learning for reliability). Order this part first — it's the long pole in getting the board built.

**Ground return path — layout guidance, not a component.** The 4-layer stackup gives a solid ground plane (L2), but a single plane doesn't automatically mean current returns behave well. The DRV8874's motor return current and the sensitive `IPROPI`/AS5600 signal paths sharing that same plane can couple noise into each other if component placement isn't deliberate. Practical guidance for layout: keep the motor power return path physically separated from the sensitive analog area, converging at a single point near the power entry — a star-point strategy even though it's technically one continuous plane, not physically split copper.

**DRV8874 power-up sequencing — flagged, not resolved.** Some H-bridge drivers have a preference for which supply (logic `VCC` vs. motor `VM`) powers up first. This hasn't been verified against the DRV8874 datasheet specifically — worth checking directly during schematic capture rather than assuming either order is fine.

---

## 5. Decisions Required Before Schematic Capture

These aren't sourcing gaps — they're design choices that determine how the schematic gets drawn. Working through them now avoids redrawing later.

| Decision | What it affects | Status |
|---|---|---|
| **DRV8874 `PMODE` (control interface)** | ✅ **Decided: PH/EN mode.** `IN1` → MCU GPIO (direction), `IN2` → MCU timer/PWM channel (speed, the current-loop output). Simplest option, one timer channel, leaves more MCU timer resources free for the encoder and anything added later. | Closed |
| **DRV8874 `IMODE` (current regulation behavior)** | ✅ **Decided: cycle-by-cycle.** When current hits `I_TRIP` (2.0A), the driver chops the output off for whatever remains of the current PWM period, then retries at the next period boundary — off-duration varies with duty cycle (see design notes below). Chosen over fixed off-time to avoid a second hardware timer that could override firmware PWM commands during a stall, keeping the current-loop behavior easier to reason about while debugging. | Closed |
| **`nFAULT` pin wiring** | ✅ **Decided: `PB2`, with a 10kΩ pull-up to 3.3V.** Open-drain, active-low fault output from the DRV8874 (overcurrent shutdown, thermal shutdown, undervoltage, charge-pump fault). `PB2` supports EXTI2 for immediate interrupt-driven fault handling rather than polling. **Tentative** until the full pin map is finalized in the STM32 pin assignment pass below — timer/encoder pin choices could still shift things. | Closed (tentative) |
| **CAN message protocol** | ✅ **Decided.** 500 kbps, standard 11-bit IDs. Command frames at `0x100+node_id` (host→node), telemetry at `0x200+node_id` (node→host). `node_id` set in firmware at flash time (no jumpers/DIP switches needed). Full payload layout below. | Closed |
| **PCB layer count** | ✅ **Decided: 4-layer.** Stackup: L1 signal/components, L2 solid ground plane, L3 power plane (3.3V + 12V), L4 signal. Chosen for EMC (dedicated ground plane rather than a pour fighting for space with signal routing, avoiding the fragmentation problem you diagnosed on ESP-Drone's 2-layer board) and to handle the compact, motor-adjacent form factor without crosstalk between the CAN pair, I²C bus, and current-sense signal. | Closed |
| **Magnet part number** | ✅ **Decided (spec confirmed, sourcing external).** 6mm diameter × 2.5mm thick, diametrically magnetized NdFeB, N35–N42 grade — confirmed against the AS5600 datasheet. **Not stocked locally**: checked UGE, Micro Ohm, and Future Electronics directly — none carry a standalone diametric magnet, and the Micro Ohm AS5600 module ships without one (currently also out of stock). Source via AliExpress (commonly listed for AS5600/AS5048 use) or a specialty magnet supplier. Low-stakes, cheap, doesn't block schematic capture or PCB ordering — only needed at mechanical bring-up. | Closed |
| **H-bridge PWM switching frequency** | ✅ **Decided: 20kHz.** Sits at the edge of the audible range (below ~20kHz, motor windings produce audible switching whine), matches the top end of the current loop's target bandwidth (10–20kHz) rather than falling short of it, and keeps DRV8874 switching losses low. Timer resolution checked and not a constraint: at the STM32's 72MHz timer clock, 20kHz gives 3600 discrete duty-cycle steps (~0.028% resolution). Consistent with the `T=50µs` assumption already used in the earlier current-limiting walkthrough. | Closed |
| **VM-side bulk capacitance / transient protection** | ✅ **Decided: 220–330µF/25V electrolytic + 0.1–1µF ceramic** at the DRV8874's VM pin. See §3.2 BOM for the sizing calculation. | Closed |

### 5.1 CAN Protocol Definition

**Bit rate:** 500 kbps — standard for short-distance robotics CAN, comfortable margin at this bus length/node count.

**Frame format:** Standard 11-bit ID (not extended). 2048 possible IDs is far more than needed for a handful of motor nodes; extended IDs add complexity with no benefit at this scale.

**ID allocation:**
```
Command IDs:    0x100 + node_id   (host → motor node)
Telemetry IDs:  0x200 + node_id   (motor node → host)
```
`node_id` is set in firmware at flash time — no jumpers or DIP switches, one less connector and one less thing to get wrong in layout. Node 1: commands on `0x101`, telemetry on `0x201`. Node 2: `0x102`/`0x202`, and so on. `0x000`–`0x0FF` reserved for future bus-wide messages (broadcast, emergency stop).

**Command frame** (host → node, ID `0x100+n`, 8 bytes):

| Bytes | Field | Type |
|---|---|---|
| 0–3 | Setpoint value | `float32` |
| 4 | Control mode (0=position, 1=speed, 2=current) | `uint8` |
| 5–7 | Reserved | — |

**Telemetry frame** (node → host, ID `0x200+n`, 8 bytes):

| Bytes | Field | Type |
|---|---|---|
| 0–3 | Current position | `float32` |
| 4–5 | Current motor current (mA) | `uint16` |
| 6 | Fault flags (bit 0=overcurrent, bit 1=stall, etc.) | `uint8` |
| 7 | Reserved | — |

Both directions fit in a single classic CAN frame — no multi-frame reassembly needed. Since the full cascaded PID loop (current→speed→position) runs locally on each node, the bus only ever carries setpoints and status, not raw control-loop data, so bandwidth is not a concern even with several nodes sharing the bus.

### 5.2 STM32 Pin Assignment (running tracker — built incrementally)

Populated as each decision above locks in a pin. Not final until every row is filled.

| Pin(s) | Function | Status | Note |
|---|---|---|---|
| `PA13`, `PA14` | SWD (program/debug) | Fixed | Never available for reassignment |
| `PB8` | CAN1_RX (bxCAN, remapped) — SN65HVD230 `R`/RXD pin drives this | Assigned | Full remap (`AFIO_MAPR CAN_REMAP=10`), off default `PA11` to keep it free of the USB/CAN SRAM-sharing constraint entirely |
| `PB9` | CAN1_TX (bxCAN, remapped) — drives SN65HVD230 `D`/TXD pin | Assigned | Full remap, off default `PA12`. Direction matches the CAN adapter board's PA12(TX)/PA11(RX) wiring (§8) — TX always drives the transceiver's D input, RX always reads the transceiver's R output |
| `PB6`, `PB7` | I²C1 (AS5600 encoder) | Reserved | Default I²C1 pins |
| `PB2` | `nFAULT` (DRV8874) | **Tentative** | EXTI2-capable, no conflicts yet — may shift once timer pins below are chosen |
| `PA5` | `IN1` — direction (DRV8874, PH/EN mode) | Assigned | Plain GPIO output, no special peripheral needed |
| `PA6` | `IN2` — PWM speed (DRV8874, PH/EN mode) | Assigned | `TIM3_CH1`, no remap needed. TIM4 deliberately avoided — its default pins overlap I²C1 (`PB6`/`PB7`) and the remapped CAN pins (`PB8`/`PB9`) |
| `PA0` | `IPROPI` → ADC (current sense) | Assigned | `ADC1_IN0`. **This pin was missing from the tracker entirely until now** — the current-sense signal needs an ADC-capable pin same as any other input, and it hadn't been assigned. Caught while closing out `IN1`/`IN2`. |

**Pin tracker complete.** Every signal identified so far has a home with no conflicts.

**Encoder timer input — resolved, not needed.** Hardware encoder-timer mode exists for reading raw A/B quadrature pulse trains, which is what the mechanical `YT06-OP` encoder from earlier comparisons would have produced. The AS5600 doesn't work that way — it's read over I²C as an absolute angle value on demand, with no pulse stream to lock a hardware timer onto. Position is read by issuing an I²C request each control-loop tick (~100Hz per the cascaded-loop plan), not by counting pulses. No pin or peripheral needed beyond the I²C1 bus already reserved above.

---

## 6. Open Items Before Schematic Capture

- [x] ~~Confirm target motor and its expected stall/running current~~ → **JGA25-370, 12V, 133 RPM: free-run 50 mA, stall 1.2 A**
- [x] ~~Size `R_IPROPI`~~ → **2.2 kΩ**, full-scale ADC at ~3.3A
- [x] ~~Confirm buck inductor value~~ → **68 µH, `CD54-680M`, fully specified — see item below**
- [x] ~~Add crystal oscillator (was missing entirely from the BOM)~~ → **8MHz, 3225-SMD, C_L=20pF, UGE Electronics Egypt — C1=C2=20pF load caps**
- [x] ~~Calculate the VREF resistor divider values~~ → **R1 = 3.3kΩ, R2 = 5.1kΩ**, gives VREF ≈ 2.0V, I_TRIP ≈ 2.0A. Add 100nF filter cap at the VREF node.
- [x] ~~Assign real STM32 pins for `IN1`/`IN2`~~ → **`IN1`=`PA5`, `IN2`=`PA6`(`TIM3_CH1`)**. Also caught and assigned `IPROPI`→**`PA0`(`ADC1_IN0`)**, which had no pin at all until now.
- [x] ~~Check AMS1117-3.3's minimum output capacitor~~ → **22µF tantalum output, 10µF tantalum/electrolytic input** — ceramic avoided due to ESR mismatch with the regulator's stability requirement (0.3–22Ω range; typical ceramic ESR is far below that)
- [x] ~~Size the VM-side bulk capacitor~~ → **220–330µF/25V electrolytic + 0.1–1µF ceramic**, sized from an energy estimate at I_TRIP
- [x] ~~Decide CAN connector standard~~ → **JST-XH 2.5mm, 3-position (CAN-H/CAN-L/GND), two per board for daisy-chain topology**
- [x] ~~Confirm the H-bridge PWM switching frequency~~ → **20kHz**, edge of audible range, matches current loop's target bandwidth ceiling
- [x] ~~Pick an exact 68µH inductor part number~~ → **`CD54-680M`, DCR 0.46Ω max, IDC 0.61A max — datasheet-confirmed, no outstanding verification needed**
- [x] ~~Design reset circuit~~ → **100nF cap + momentary pushbutton on `NRST`→GND**, no external pull-up needed (internal ~40kΩ built into the chip)
- [x] ~~Decide `BOOT0` pin strapping~~ → **Fixed 10kΩ pull-down to GND**, no jumper — SWD/ST-Link programming never needs the system bootloader
- [x] ~~Add reverse-polarity protection on the 12V input~~ → **Series Schottky diode, reusing the buck stage's catch diode part (3A SS34-class)** — placed in +12V line before the split to DRV8874 VM and the buck stage
- [x] ~~Add ESD/transient protection on CAN bus lines and motor connector~~ → **CAN: `NUP2105L` dual-channel TVS array, confirmed local at UGE, industry-standard CAN-specific part. Motor: generic bidirectional TVS across terminals, lower priority but included.**
- [x] ~~Finalize I²C pull-up value~~ → **4.7kΩ, calculated and confirmed against the I²C-bus spec formula (valid range 966Ω–23.6kΩ for this bus), not just assumed**
- [x] ~~Pick specific rated parts for the power input and motor output connectors~~ → **2-pin, 5.08mm screw terminal (10–16A rated), same part reused for both — confirmed local at UGE and Micro Ohm, ~5–7× headroom over actual worst-case current (~2.1–2.2A)**
- [x] ~~Decide the physical implementation of the CAN termination jumper~~ → **2-pin, 2.54mm pin header + removable shunt cap, in series with the 120Ω resistor** — matches CVRA's reference design, supports future daisy-chain reconfiguration without a soldering iron
- [x] ~~Wire AS5600 power pins correctly for 3.3V single-supply operation~~ → **`VDD5V` and `VDD3V3` tied together, both fed from 3.3V rail, plus a 1µF cap on the internal LDO pin — real datasheet requirement, previously missed**
- [x] ~~Specify STM32 decoupling capacitors~~ → **Precise count: 3× 100nF (digital VDD pins) + 4.7µF bulk + 100nF on VDDA with series ferrite bead — VDDA isolation directly protects the current-sense ADC reading, the whole reason for the two-stage power architecture**
- [x] ~~Note DRV8874 thermal pad handling~~ → **Via-stitching to copper pour required, HTSSOP-16 PowerPAD package, relevant given regular `I_TRIP` chopping events**
- [x] ~~Add local decoupling for SN65HVD230 and DRV8874 VCC~~ → **100nF each, standard practice, previously unlisted**
- [x] ~~Assign SN65HVD230 `RS` and `Vref` pins~~ → **`RS` tied directly to GND (high-speed mode, no standby/sleep needed); `Vref` left floating (N/C) since standard, not split, termination is used** — datasheet-verified, closed via direct cross-check against `SN65HVD230` datasheet during schematic capture
- [x] ~~Document CAN1_TX/RX direction on the remapped `PB8`/`PB9` pins~~ → **`PB8`=CAN1_RX (from transceiver `R`/RXD), `PB9`=CAN1_TX (to transceiver `D`/TXD)** — previously listed as a combined "CAN" pair with no direction; now matches the CAN adapter board's PA11/PA12 wiring convention exactly
- [x] ~~Add a power-on indicator~~ → **LED + series resistor on the 3.3V rail — genuinely missing until this audit, no "is it alive" signal existed anywhere**
- [x] ~~Add main PCB mounting holes~~ → **4× M3, corner-placed, standard JLCPCB clearance — nothing addressed how this board physically attaches to anything**
- [x] ~~Specify the AS5600 sub-PCB link connector~~ → **JST-SH, 1.0mm, 4-position — closes the earlier vague "short cable" description**
- [x] ~~Add bring-up test points~~ → **3.3V, 5V, VM, IPROPI — cheap, aids the multi-stage bring-up sequence in §7**
- [x] ~~Address ground return path routing~~ → **Layout guidance added (§4): keep motor return current physically separated from the sensitive analog area, star-point convergence near power entry, even on one continuous plane**
- [x] ~~Decide AS5600 `DIR` pin handling~~ → **3-pad solder jumper (`JP1`)**, center=`DIR`, sides=`+3V3`/`GND` — defers CW/CCW polarity to assembly time rather than guessing at schematic time
- [x] ~~Terminate AS5600 `OUT`/`PGO` pins~~ → **Both No-Connect** — `OUT` unused (I²C read, not analog/PWM), `PGO` floats on its internal pull-up (I²C programming via Option A, not the OUT-pin Option B path)
- [x] ~~Reconcile AS5600 decoupling values with the actual 3.3V-mode datasheet diagram~~ → **`C1=100nF` + `C2=10µF`** (matches datasheet Fig. 13's 3.3V-operation diagram; the earlier "1µF" note referenced the 5V-mode LDO table, which doesn't apply once `VDD5V`/`VDD3V3` are tied together)
- [x] ~~Confirm all five schematic subsystem sheets are drawn~~ → **Power Stage, MCU Core, Motor Drive, CAN Bus, and Sensing all complete in KiCad**
- [x] ~~Add motor output connector protection~~ → confirmed present in schematic (generic bidirectional TVS across terminals, per §3.4)
- [x] ~~Add main PCB mounting holes to schematic~~ → confirmed present (4× M3, corner-placed)
- [ ] **Flagged, unresolved:** DRV8874 power-up sequencing (VCC vs. VM order) — not verified against the datasheet, check during schematic capture
- [ ] **New, before ERC/layout:** cross-check main-board ↔ AS5600 sub-PCB connector pin order matches 1:1 (§3.4) — both footprints were placed independently and haven't been diffed against each other yet

- [~] ~~Design the AS5600 mounting bracket~~ → **Spec drafted (§9), but finalization deliberately deferred until the AS5600 sub-PCB layout is confirmed** — same logic as the CAN adapter firmware deferral
- [ ] **External, in progress:** source DRV8874 internationally
- [ ] **External, in progress:** source a *confirmed diametrically-magnetized* magnet — verify magnetization type before buying anything local

---

## 7. Build Sequence

1. Schematic capture (CAN node + power stage + DRV8874 + AS5600), reference CVRA/Cormack boards
2. ERC clean
3. Layout — Kelvin considerations mostly retired by DRV8874's integrated sense, but power-trace sizing and switching-node layout on the buck stage remain the core exercise
4. DRC clean, JLCPCB stackup check, order
5. Bring-up: power on, confirm 3.3V rail, confirm CAN enumerates, confirm AS5600 reads a sane angle at standstill, *then* close loops one at a time — current first, then speed, then position
6. Bring up the CAN adapter (§8) and use it from a laptop to send real command frames (`0x101`) and read telemetry (`0x201`) back from the motor board — this is what actually proves the CAN half of the board works, not just that it powers on

---

## 8. CAN Adapter (Supporting Tool — Separate Board)

Not part of the motor controller node itself — this is a second, small board whose only job is letting your laptop send/receive real CAN frames to test board #1. Not confirmed available locally as a ready-made purchase (checked UGE, Micro Ohm, Future Electronics — nothing found), so this is a build, using parts already on hand or already being sourced for the main board.

**Why a second chip, not the motor board's own USB:** on the STM32F103, the CAN peripheral and USB peripheral share the same SRAM block and can't run simultaneously. A USB-CAN bridge needs both active at once by definition, so this can't run on the motor board's own MCU, and can't be merged onto the same board as a second chip either without effectively building two boards fused together for no real benefit — better to keep it fully separate and reusable for future CAN nodes too.

### 8.1 Hardware

| Part | Role | Source |
|---|---|---|
| Blue Pill (STM32F103C8T6) | Runs the bridge firmware | Already owned, same as maglev board |
| `SN65HVD230` | CAN transceiver — talks to the bus | Same part as the motor board's BOM — source a second one |
| USB-to-UART module (CH340G or FT232) | Bridges PC USB ↔ Blue Pill UART | New, cheap, common — same sourcing tier as passives |
| ST-Link programmer | Flashes the firmware | Already owned |

### 8.2 Wiring

**Power:** no separate design needed — the Blue Pill's onboard 5V→3.3V regulator handles everything, powered directly from the USB connection to the laptop. The `SN65HVD230` taps 3.3V from the Blue Pill's own regulated output.

**Termination:** with exactly two devices on the bus (this adapter and the motor board), **both ends need their `120Ω` termination jumper enabled** — they're the only two physical points on the wire. If a third node is ever added later, this changes: only the two true physical ends of the bus stay terminated.

**CAN transceiver to STM32** (native default pins — safe here since USB is never used on this chip):
```
SN65HVD230 VCC  → STM32 3.3V
SN65HVD230 GND  → STM32 GND
SN65HVD230 TXD  → STM32 PA12 (CAN1_TX)
SN65HVD230 RXD  → STM32 PA11 (CAN1_RX)
```

**CAN transceiver to the bus** — same 3-pin JST-XH standard (CAN-H, CAN-L, GND) as the motor board, with the same `NUP2105L` TVS protection at the connector (see main board §3.4 for the part). This adapter becomes the second physical end of the bus, so its `120Ω` termination jumper needs to be enabled.

**USB-UART bridge to STM32:**
```
Bridge TX  → STM32 PA10 (USART1_RX)
Bridge RX  → STM32 PA9  (USART1_TX)
Bridge GND → STM32 GND
Bridge USB connector → laptop
```

### 8.3 Firmware and PC side

**Firmware approach — decided, deferred until after both PCBs are designed:** write the SLCAN-over-UART bridge firmware from scratch rather than adapting an existing open-source implementation. Chosen deliberately over the faster path, since it's a small, well-scoped, self-contained firmware task (parse text commands over UART → translate to `bxCAN` register calls → encode received frames back to text) that's genuine CAN/embedded skill-building in its own right, consistent with the rest of this project's purpose. **⚠ Do not start this until schematic + layout for both the motor board and this adapter board are finished — this is a reminder for both of us to come back to it, not a task to pick up mid-PCB-design.**

Flash via SWD/ST-Link, same process as any other STM32 board. On the PC, the bridge module enumerates as an ordinary COM/serial port. `python-can` talks to it directly once the firmware exists:

```python
import can
bus = can.interface.Bus(channel='COM5', bustype='slcan', bitrate=500000)

# Send a command: node 1, position mode, setpoint = 90.0 degrees
msg = can.Message(arbitration_id=0x101, data=[...float32(90.0)..., 0x00], is_extended_id=False)
bus.send(msg)

# Read telemetry back (arrives on 0x201)
response = bus.recv(timeout=1.0)
```

### 8.4 Full data path

```
Python script → USB → CH340/FT232 → UART → STM32 (SLCAN firmware)
    → bxCAN peripheral → SN65HVD230 → CAN-H/CAN-L → motor board's SN65HVD230
    → motor board's STM32 → motor board's control loop firmware
```

---

## 9. AS5600 Mounting Bracket (Mechanical Spec — SolidWorks Task)

**Confirmed motor dimensions** (cross-checked across manufacturer manual and independent listings): body diameter **25mm**. Front output shaft: 4mm diameter × 9.5mm length (not relevant to this bracket — it's the rear shaft stub that matters here). **Rear shaft stub dimensions are not published anywhere** — checked the manufacturer manual and multiple retailer listings, only the front shaft is dimensioned. Design around this gap rather than guessing a number (see adjustment allowance below).

**Structure:** a small clamp/collar sized to the motor's confirmed 25mm body OD, with an arm extending to the rotation axis holding the AS5600 sub-PCB at the correct standoff. The rear end of this motor has no mounting holes to bolt to — the datasheet's `2× M3, 4.5mm deep, 17mm spacing` holes are on the gearbox/front end, for chassis mounting, not the bare motor can — so this has to be a clamp, not a bolt-on bracket.

**Magnet mounting:** glued flat onto the shaft stub's end face, centered on the rotation axis — see §3.3 sensing table for why this avoids needing the unpublished shaft diameter.

**Air gap target:** 1.0–1.5mm between the magnet and the AS5600 die (within the datasheet's 0.5–3mm working range, biased toward the lower/tighter end for best signal strength).

**Handling the unconfirmed shaft length:** design the standoff arm with a **slot rather than a fixed hole**, giving a few millimeters of adjustment travel. Tune the actual air gap once the motor physically arrives and the real shaft protrusion can be measured directly — consistent with the same "confirm against the physical part" approach already used elsewhere for this build (e.g. motor socket ID, battery bay sizing on other projects).

**Status:** Spec drafted (motor dimensions, clamp approach, magnet mounting method, air gap target) but **finalization deliberately paused** until the sub-PCB layout is confirmed — the bracket needs to interface with real mounting holes and the cable exit point on the actual AS5600 sub-PCB, neither of which exist yet. Same logic as the CAN adapter firmware deferral in §8.3: this is a reminder to return to it once the PCB is laid out, not a task to finish speculatively now.

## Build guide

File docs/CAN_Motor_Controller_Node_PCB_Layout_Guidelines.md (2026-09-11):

# CAN Motor Controller Node — PCB Layout Guidelines

**Companion document to `CAN_Motor_Controller_Node_Spec.md` — layout phase only.**
**Status:** Schematic capture complete (5/5 subsystem sheets, ERC clean). This document covers placement, routing, plane strategy, and DRC targets for the layout phase that follows.
**Scope:** This file is deliberately separate from the main spec. The spec owns *what* is on the board and *why*; this file owns *where it goes and how it's wired physically*. Keep them separate — don't let layout notes drift back into the spec or vice versa.

---

## 1. How to use this document

Read once before placement, then again before routing. The two passes catch different classes of mistake:
- **Before placement:** §3 (floorplan) and §4 (placement rules) — cheap to fix now, expensive after traces exist.
- **Before routing:** §2 (trace sizing, including via strategy in §2.4), §5 (plane strategy, including L1/L4 fill in §5.2), §6 (CAN specifics), §7 (thermal) — these shape how you draw each net.
- **Before ordering:** §8 (DRC/manufacturing) and §9 (pre-submission checklist).

---

## 2. Trace sizing

### 2.1 Power nets

| Net | Worst-case current | Min width (1oz Cu, 10°C rise, IPC-2221 external layer) | Recommended |
|---|---|---|---|
| VM / motor traces (12V → DRV8874 → motor) | 2.0–2.2A (I_TRIP-capped) | ~0.75–0.8mm (30–32mil) | **1.0–1.25mm (40–50mil), or a poured copper zone** |
| 12V input, pre-reverse-protection-diode | 2.1–2.2A | same as above | Pour from screw terminal through diode footprint to the VM split point |
| 5V intermediate rail (buck output → LDO input) | ~100–150mA | trivial by ampacity | 0.5mm (20mil) — sized for low impedance, not current capacity |
| 3.3V rail | ~100–150mA | trivial by ampacity | 0.5–0.6mm, or a poured zone. This rail is the ADC's indirect reference via VDDA — impedance matters more than ampacity here |
| I²C, GPIO, digital control | mA-level | n/a | 0.2mm (8mil) standard |
| CAN-H / CAN-L pair | mA-level | n/a | 0.2mm (8mil), matched pair — see §6 |

**Why VM/motor traces are oversized relative to bare ampacity:** at 2A, IPC-2221 only demands ~30mil. The extra margin isn't about heating — it's about keeping resistance (and therefore voltage sag during I_TRIP chopping events) low, since that sag is exactly the noise source the VM bulk cap is sized to absorb. A resistive trace partially undoes that capacitor's job.

**If board space forces narrower traces:** JLCPCB offers 2oz copper for a modest upcharge — halves the required width for the same current/temperature rise. Use this rather than shaving the VM/motor width below 30mil.

**Preferred approach for VM/motor current:** don't hand-route these as traces at all where avoidable. Pour a dedicated copper zone from the input connector, through the reverse-protection diode, to the DRV8874 VM pin and bulk cap. Narrow to a routed trace only where it must squeeze past another feature.

### 2.2 Why 5V doesn't get the same pour treatment as VM

The 5V intermediate rail (buck output → LDO input) is a trace, not a pour, and deliberately so — the factors that justified pouring VM don't apply here:

| Factor | VM/12V | 5V intermediate |
|---|---|---|
| Current | 2.0–2.2A, with I_TRIP transients | ~100–150mA steady, no chopping events |
| Physical run | Spans the board: input connector → diode → splits to buck input and DRV8874 VM | Short, local hop between the buck output cap and LDO input cap, which sit adjacent in the floorplan specifically to keep this run short |
| Noise sensitivity | Sag here couples directly into current-sense noise | Already accepted as noisy by design — that's the entire reason the LDO exists downstream. A lower-impedance trace doesn't protect anything the LDO isn't already cleaning up. |

**0.5mm (20mil)** trace is sufficient (already reflected in §2.1's sizing table), routed as a short, direct hop on whichever outer layer the two caps land on. If a layer change is unavoidable, 1–2 vias are enough — this is a single crossing, not a current-stitching job like §2.4. No third L3 zone is warranted for this net; adding one would mean another clearance boundary to route around for a net that never needed the impedance reduction a pour buys.

### 2.3 Signal nets

- Standard digital (GPIO, I²C, control lines): 0.2mm (8mil) — comfortably within JLCPCB standard tier.
- CAN differential pair: 0.2mm (8mil) traces, routed as a matched pair (see §6). Controlled impedance to a specific target (e.g. 120Ω differential) is not critical at 500kbps — matched routing and noise isolation matter more than a precise impedance number here.

### 2.4 Via strategy for VM/12V power nets

**Why vias at all, here:** VM/12V current is carried primarily as an **L3 copper pour**, not an outer-layer trace (see §5 for the plane split rationale). Every VM-carrying component pad on L1/L4 needs to reach that L3 pour through a cluster of vias — never a single via — dropping straight down from the pad into the pour. The pour itself does the job of "connecting everything together"; the vias are just the entry points into it.

**Two via classes cover the whole board:**

| Class | Drill / pad | Approx. current capacity per via* | Use for |
|---|---|---|---|
| **Standard power via** | 0.3mm drill / 0.6mm pad | ~0.8–1A (10°C rise, 1oz Cu) | Most VM/12V connections |
| **Thermal/high-density via** | 0.3mm drill / 0.6mm pad (same size, arranged as a grid) | same per-via, aggregated | DRV8874 thermal pad specifically |

*Via current-capacity figures vary by calculator and are conservative by design — treat them as a floor, not a tight budget. Don't go below 0.3mm drill for anything carrying real current: resistance and reliability both suffer below that, without meaningfully saving board area.

**Per-component via count:**

| Node | Worst-case current | Via count | Why this many |
|---|---|---|---|
| Input connector → VM net | ~2.2A | **4× 0.3mm** | Full board current passes through here first — most current-critical single point on the board |
| Reverse-protection diode, anode pad | ~2.2A | **3× 0.3mm** | Small SMA/DO-214 pad area — tightest current-density squeeze point on the board; watch this in the footprint |
| Reverse-protection diode, cathode pad | ~2.2A | **3× 0.3mm** | Same bottleneck, other side |
| DRV8874 VM pin | up to 2.0A (I_TRIP) | **4× 0.3mm** | High *dI/dt*, not just DC average — this is where current chops on/off every switching cycle, so low inductance matters as much as ampacity |
| VM bulk cap, positive terminal | transient/ripple, up to ~2A | **3–4× 0.3mm** | Absorbs energy during I_TRIP events — needs a low-impedance path into the plane |
| VM bulk cap, negative/ground terminal | same magnitude, return path | **3–4× 0.3mm → L2 ground** (not the VM plane) | Part of the star-point ground convergence (§5) — same current magnitude as the positive side, so same via count, but stitches to ground rather than VM |
| LM2596 input (Vin) pin | ~100–150mA (buck's own draw) | **2× 0.3mm** | Ampacity alone needs 1, but a single via is a single point of failure and an unnecessarily high-inductance connection — never leave any power node on exactly one via |
| DRV8874 thermal pad (PGND) | thermal + power-ground return | **6–9× 0.3mm**, grid across the pad | Doing double duty: heat dissipation *and* PGND stitching — check the datasheet, the exposed pad ties internally to power ground, so this grid is also the switching-current ground return, not just thermal relief |

**Two things happening at once, and they don't always agree:**
- **Ampacity** scales with current — why the input connector, diode, and DRV8874 VM pin get 3–4 vias while the LM2596 input gets only 2.
- **Inductance / dI-dt** matters independently of average current — why the DRV8874 VM pin gets as many vias as the diode despite lower average current. Its current is chopping at 20kHz; a low-inductance connection matters for switching noise even when the RMS number looks manageable.

**Zone fill / thermal relief:** when the L3 VM pour is drawn as a copper zone, check the pad-connection style for high-current pads. Default thermal-relief spokes (four thin connecting legs) are meant for hand-soldering ease and add resistance exactly where it's unwanted on this net. For the DRV8874 VM pin and the VM bulk cap especially, set the pad connection to **solid fill** rather than thermal relief — reflow assembly doesn't need the thermal isolation the way hand soldering does.

**KiCad practicalities:**
- Set up a dedicated net class (e.g. `VM_HIGH_CURRENT`) with the 0.3mm/0.6mm via and 40–50mil trace width as class defaults, rather than manually overriding each net.
- The DRV8874 thermal pad via grid is usually a manual placement in the footprint editor, not something the net class or autorouter handles sensibly on its own — place that one deliberately.
- After the L3 zones are filled, visually re-check that the VM/3.3V pour boundary doesn't cross under the CAN pair, crystal, or I²C bus (§4.1, §5) — easy to lose track of once looking at a filled zone instead of the planned boundary line.
- Crystal (OSC_IN/OSC_OUT) and load-cap traces: shortest possible, standard signal width, no other signal routed parallel or underneath.

---

## 3. Floorplan — physical zones

Map the five schematic sheets to physical board regions. The goal is to let the electrical "quiet" and "noisy" boundaries coincide with the geographic ones, so a single ground-plane split (if used on L3) can follow a sensible line.

```
┌─────────────────────────────────────────────┐
│  [PWR IN]      [BUCK STAGE]   [MCU CORE]     │
│  screw term →  LM2596,        STM32,         │
│  reverse-prot  inductor,      crystal,       │
│  diode → VM    diode →        NRST, BOOT0,   │
│  bulk cap      LDO input      SWD header     │
│                                                │
│  ───────────── quiet / noisy boundary ──────  │
│                                                │
│  [MOTOR DRIVE]                [CAN]           │
│  DRV8874, VREF divider        SN65HVD230,     │
│  + filter cap, motor          NUP2105L,       │
│  output connector,            CAN connectors, │
│  second VM bulk cap           termination     │
│                                jumper         │
│  ─────────────────────────────────────────    │
│                [SENSING]                       │
│                I²C pull-ups,                   │
│                JST-SH → AS5600 sub-PCB         │
└─────────────────────────────────────────────┘
```

**Rationale:**
- Power-in and buck stage anchor one edge — where the 12V cable physically enters anyway.
- MCU core sits as the quiet island, geographically buffered from both switching zones.
- Motor drive occupies its own corner as the single noisiest block on the board (highest dI/dt, highest current).
- CAN sits on the *opposite* side from motor drive — it has its own external cable and shouldn't share an edge with the H-bridge.
- Sensing/I²C is pushed as far from motor drive as the floorplan allows — no error correction on that bus, so it gets the most protective placement despite being electrically the lowest-power signal on the board.

**Note:** placement within a zone still needs a second check beyond the zone assignment itself — see §4.4 for the zone-adjacent vs. loop-adjacent distinction, using the AMS1117's placement relative to the buck stage as a worked example.

---

## 4. Placement rules

### 4.0 Proximity to the DRV8874 — proximity isn't a single rule

"Away from the DRV8874" is not a blanket distance requirement from the part as a physical object — several things are *forced* to sit right next to it and are fine there. The real driver is **signal character**, not raw distance:

- **Functionally close, and correctly so:** VCC decoupling cap, VREF filter cap, VM bulk cap, the thermal pad via grid, IN1/IN2 (from STM32), nFAULT and its pull-up, and the motor output traces themselves. These either exist specifically to catch noise at the source, or are digital/logic-level connections with enough noise margin (crossing ~1.65V to flip state on a 3.3V rail) that nearby switching noise doesn't threaten them. Pushing these away would only add inductance and trace length for no protective benefit — don't try to apply §4.1's distance logic to this group.
- **Genuinely needs distance:** anything analog, timing-critical, or without error correction — the crystal, the I²C bus, the CAN pair, and the *routing* of the IPROPI trace once it leaves the DRV8874 pin (the pin itself is unavoidably on the part; where the trace goes afterward is the part that matters). These have little to no noise margin, and that's what §4.1 is actually protecting.

Read §4.1 as "keep the low-margin signals away from the switching node and motor-current loop specifically," not "keep everything away from the DRV8874 except caps."

### 4.1 Keep apart — non-negotiable

| Pair | Why | Guidance |
|---|---|---|
| Crystal ↔ buck stage / DRV8874 | Crystal is the most sensitive net on the board; switching noise coupling here corrupts the CAN bit-timing reference | ≥10mm physical separation as a target on this board size. No switching trace routed near or under the crystal or its load caps. |
| I²C pair ↔ motor / switching traces | No error correction on I²C; coupled noise = silent bad reads | Don't route SDA/SCL parallel to or alongside motor output traces or the buck switching node. Cross perpendicular only, never parallel-adjacent. |
| IPROPI trace (DRV8874 pin → PA0) ↔ motor power traces | Small current riding through a noisy neighborhood the whole way to the ADC | Route on an inner layer where possible, referenced to solid L2 ground for the full run. Don't let it parallel the motor traces for any distance, even though R_IPROPI itself sits at the STM32 end. Full via-routing procedure and layer choice: §5.4. |
| CAN-H/CAN-L ↔ buck switching node / motor traces | Crosstalk into a differential pair from an adjacent single-ended noisy trace degrades signal integrity even at CAN's relatively low speed | No parallel runs near switching nets. |

### 4.2 Keep close — deliberately

- Every decoupling cap: <2mm from its pin where layout allows, dedicated via to ground plane at the cap's ground pad (not shared with another net's return).
- VREF filter cap (100nF): directly at the DRV8874 VREF pin. A long trace between the divider and the cap partially defeats the cap's purpose (catching switching noise before the trip comparator sees it).
- DRV8874 VCC decoupling cap: at the VCC pin, but *not* sharing a via/ground stub with the VM bulk cap's ground return — different current personalities (logic supply vs. motor power return) even though both land on the same plane.
- VM bulk cap: directly at the VM pin — trace/pour length between them reintroduces the inductance the cap exists to defeat.
- Thermal pad via grid: on the part itself, by necessity (§7.1).
- IN1/IN2 (DRV8874 control inputs, from STM32) and nFAULT + its pull-up: land wherever convenient near the DRV8874. These are digital, logic-level signals with real noise margin — not a noise risk in the way an analog or timing signal is, so there's no benefit to routing them the long way around to gain distance.
- Test points: reachable from one side of the board with a probe. Don't bury behind the motor connector or under the CAN header.

### 4.3 The tightest loop on the board

The LM2596 switching node — SW pin → inductor → catch diode — should be treated as its own small island. Inductor and diode placed immediately adjacent to the SW pin, loop area minimized above all else in this zone. This is the single highest-priority tight-loop for EMC on the entire board; everything else in §4 is secondary to getting this one right.

### 4.4 Zone-adjacent vs. loop-adjacent — two different questions about the same placement

These sound similar but answer different concerns, and a component can pass one while failing the other. Worth checking both separately for anything placed near the buck stage or the motor drive zone.

**Zone-adjacent** means two components sit in the same region of the floorplan (§3) — a coarse-grained placement decision based on functional/net relationship. The AMS1117 is zone-adjacent to the LM2596 because it's the next stage downstream in the power chain; putting it in the same neighborhood keeps the 5V trace between them short (§2.2). This is correct and intentional.

**Loop-adjacent** is a tighter, independent concern: is a component sitting physically close to — or worse, overlapping — a *specific* high-dI/dt current loop, regardless of which zone that loop lives in. The SW-inductor-diode loop (§4.3) radiates a real local magnetic field at 150kHz with fast switching edges; anything crowded directly against it can have noise coupled in through that field alone, independent of trace routing or ground-plane quality.

**Why both have to be checked separately:** being in the right zone doesn't protect a component from being too close to a specific noisy loop inside that zone. The AMS1117 is a working example — it should be zone-adjacent to the buck stage (short 5V trace, §2.2), but *not* loop-adjacent to the SW-inductor-diode loop specifically, since its whole job is delivering a clean rail to VDDA (the ADC reference IPROPI is measured against). Noise picked up here through proximity to the switching loop would leak into the current-sense reading through a different path than the one the two-stage power architecture was built to avoid (spec §4). Concretely: place the LDO and its caps on the *output* side of the switching loop, oriented so the loop isn't facing directly at them — a few mm and orientation is enough, not crystal-level separation (§4.1's ≥10mm is a different, larger concern).

---

## 5. Ground / power plane strategy

Stackup (already locked): **L1 signal, L2 solid ground, L3 split power (VM/3.3V), L4 signal.**

- **L3 will need a split** between the 3.3V zone and the VM/12V zone — same layer, different nets. Route that split to run under the geographic boundary between the MCU/sensing zone and the power/motor zone (§3), so the electrical and physical boundaries agree.
- **Do not let the L3 split pass underneath:** the CAN pair, the crystal, or the I²C bus. Any signal on L1/L4 that needs a clean return path will find a discontinuity if the plane directly beneath it is split — see §5.3 for why this matters more than it might seem.
- **Star-point convergence:** VM bulk cap ground, motor output connector ground, and DRV8874 ground should all converge at one point near the power input. That convergence point is also where the "quiet" ground (MCU, CAN, sensing) ties in — not scattered vias dropped wherever a component happens to land.
- **L1 is directly adjacent to L2.** A sensitive signal routed on L1 gets L2's solid, unsplit ground as its immediate reference — the ideal case.
- **L4 is directly adjacent to L3, not L2.** L3 sits physically between L2 and L4 in the stackup, so a signal on L4 references the *split* power plane, not the solid ground plane, unless the local L4 ground flood (§5.2) is doing the work instead. This is an easy mix-up to make when thinking "L1 or L4 both work the same" — they don't. Treat L1 as the preferred layer for anything genuinely sensitive; treat L4 as workable only where the local ground flood and stitching vias (§5.2) are actually present and unbroken along the signal's path.

### 5.1 L2 is solid — L3's split does not apply here

**L2 is one single, continuous, unsplit ground pour across the entire layer** — no slots, no boundaries, one GND net covering the whole plane. This is different from L3, which is deliberately split into separate VM and 3.3V zones. Don't confuse the two: the star-point convergence discussed above is about *where on the one continuous L2 plane* each net's return current enters (via placement discipline), not about cutting the ground copper itself.

**L3 zone-to-zone clearance:** the VM zone and 3.3V zone on L3 are different nets, so KiCad enforces a clearance gap between them and DRC will flag insufficient spacing. At this voltage difference (~9V), the electrical breakdown minimum is trivial (well under 0.1mm per IPC-2221) — the real driver is manufacturing margin, not electrical necessity. Use **0.5mm (20mil)** as the zone-to-zone clearance: comfortably above JLCPCB's manufacturing floor (0.15–0.2mm standard tier), with enough slack for via placement near the boundary and some tolerance if the boundary line has to shift slightly once routing is underway. Set this explicitly in both places KiCad reads it from — the zone properties clearance field for each zone, and the net class clearance for `VM_HIGH_CURRENT` — so there's no ambiguity between the two when reading the DRC report.

Where the gap physically runs matters more than its exact width: route it along the geographic boundary between the MCU/sensing zone and the power/motor zone (§3), and after the zones are filled — not just planned — visually confirm it doesn't pass underneath the CAN pair, the crystal, or the I²C bus.

**Other L2-specific items:**
- **Board-edge clearance:** pull the L2 pour back slightly from the physical board outline (~0.25–0.3mm) rather than running copper to the edge — standard fab practice, avoids copper exposure/burring at the cut edge.
- **Mounting holes:** tie the 4× M3 mounting holes to ground by default (gives a chassis-ground path if the board ever mounts to a metal frame), unless there's a specific reason to isolate one.
- **Thermal relief on L2:** same logic as §2.4 — fine for hand-solderable low-current pads, but the DRV8874 thermal pad and VM bulk cap ground connections should be solid-filled given the current involved.

### 5.2 Ground fill on L1 and L4

Neither L1 nor L4 needs a current-carrying power pour — VM lives on L3, and 5V/3.3V distribution stays as traces near their local zones (see §2.1, §2.4). But both outer layers should still get a **flood-filled GND pour** over unused copper area, for reasons separate from current-carrying:

- **Shielding**, especially over/around the motor-drive and buck-switching zones — a grounded copper layer above the noisiest components helps contain radiated emissions rather than letting them couple into whatever's routed nearby on the opposite outer layer.
- **Extra return-path lowering** for any L1/L4 signal referencing ground — effectively parallels L2 locally.
- **Thermal spreading** — modest but free, particularly useful near the LM2596 and around the DRV8874 footprint.

**Stitch the fill to L2 with vias every 5–10mm** where component placement allows, across both L1 and L4. This keeps the outer-layer ground fill genuinely tied to the solid L2 reference rather than floating as a series of disconnected islands, and it reinforces the return path for anything routed nearby.

This fill is safe to run right up next to — even over — the crystal, CAN pair, or I²C traces. The earlier "keep apart" rules (§4.1) are about noisy *signal or switching* copper running near those nets; a grounded fill near sensitive traces is protective, not harmful, and doesn't violate those rules.

**Component-local copper that isn't a full pour but isn't a minimum-width trace either:**
- LM2596 tab — thermal pour under/around the TO-263 tab (§7.2).
- DRV8874 exposed pad — copper on L1 by definition; a small surrounding apron before the via grid takes over is normal.
- Reverse-protection diode landing pads and the input connector pad — these are the tightest current-density squeeze points (§2.4). A small widened copper polygon immediately around those pads, before the via cluster hands current down to L3, reduces localized heating right at the bottleneck.

**Check for isolated copper islands after fill.** Dense routing can pinch off a patch of L1/L4 ground pour from its stitching vias, leaving an unreferenced floating conductor — worse than no pour at all. Enable KiCad's "isolated copper" DRC check and clear any hits before finalizing.

### 5.3 Why crossing an L3 zone boundary hurts a signal — and why the detour path is the real cost

**Never route a sensitive signal so its path crosses the L3 VM/3.3V zone boundary.** This is worth understanding rather than just following, because the mechanism shows up elsewhere in this document too (§4.1, §6).

Every signal trace forms a loop: current goes out through the trace and *must* return through something. With a solid reference plane directly beneath a trace, return current naturally flows in the plane, hugging the signal's path almost exactly — tightest coupling, lowest impedance, physics doing the work for you without any deliberate routing on your part.

**A gap in that plane breaks this.** If the trace crosses over the L3 zone boundary, the return current directly beneath it hits a dead end at the gap and has to detour — around the split, through a distant via, or through weak coupling to some other plane. That detour is the actual problem, and it's worse than it sounds for two compounding reasons:

1. **Loop area balloons.** Instead of a tight loop (trace + the copper immediately beneath it), the return path now traces a long way around the gap. Loop area is directly proportional to radiated emissions *and* to susceptibility to picked-up noise — a long detour path turns a well-behaved signal into a small antenna, in both directions at once.
2. **Impedance discontinuity right at the crossing.** The signal sees a localized bump in characteristic impedance exactly where its reference disappears — reflections and ringing concentrated at one specific point on the board, right where you can least afford it on a low-margin signal.

This is exactly why L2 (never split, §5.1) is the preferred reference whenever a layer choice exists, and why the CAN pair, crystal, and I²C bus are all called out separately (§4.1) as unable to tolerate crossing the L3 gap even though each has a different underlying reason for being sensitive.

### 5.4 Worked example: routing IPROPI off L1

The IPROPI net (DRV8874 pin → PA0, feeding R_IPROPI) is a good template for handling any signal that has to escape a noisy zone via a layer change:

1. **Via at the DRV8874 pin, immediately.** Minimal exposed trace on L1 before dropping down — the less distance this signal spends on the noisy layer, the less it picks up.
2. **Route the L4 leg through the L4 ground flood (§5.2)**, not over bare L3 power copper. The local flood plus its stitching vias down to L2 gives this leg a workable, if imperfect, ground reference.
3. **Explicitly verify this leg doesn't cross the L3 zone boundary** underneath it — per §5.3, that crossing would reintroduce exactly the long-detour, high-loop-area problem the layer change was meant to avoid. This is a visual check against the filled zones, not something to assume from the floorplan sketch alone.
4. **Via back up to L1** near the STM32/R_IPROPI side — two vias total for the whole path, no more. Each transition is itself a small discontinuity; this signal needs a clean drop-and-return, not extra hops.
5. **Keep the final stretch — R_IPROPI to PA0 — as short as possible on L1.** This is the one segment carrying a voltage rather than a current, and it's the genuinely sensitive part of the whole path.

---

## 6. CAN pair — routing specifics

At 500kbps, precise controlled-impedance calculation is not critical the way it would be for a gigabit link. Do the following regardless — all free, all worth it:

- Route CAN-H and CAN-L as a matched pair: same layer, tightly coupled (spacing close to trace width), length-matched to within 1–2mm.
- No stubs off the pair between transceiver and connector.
- Continuous ground reference (L2) under the pair for its entire length — see §5 on avoiding the L3 split crossing underneath.
- Maintain physical order: NUP2105L between the connector and the transceiver, not the other way around — don't let routing convenience put the transceiver closer to the connector than the TVS array.

---

## 7. Thermal

### 7.1 DRV8874 (HTSSOP-16, exposed thermal pad)

- Stitch the exposed pad with a **grid of vias** — not one or two. Target 4–9 vias at 0.3mm drill spread across the pad area, landing directly on the L2 ground pour, which doubles as the heatsink.
- Confirm JLCPCB's via-in-pad handling (tented/filled vs. standard) for this pad before finalizing. Unfilled vias in a thermal pad can wick solder paste during reflow — a real assembly defect risk at this pad size, not a theoretical one.

### 7.2 LM2596 (TO-263)

- Generous copper pour on the tab side, even though thermal stress is lower here than at the DRV8874 given the current levels involved. Cheap insurance, no design cost.

---

## 8. Manufacturing / DRC targets (JLCPCB)

Design to these so DRC doesn't surprise you at the end. Confirm current values against JLCPCB's live capability page for your exact chosen stackup before final submission — these shift slightly by tier and revision.

| Parameter | Advanced tier | Design target (comfortable standard-tier margin) |
|---|---|---|
| Min trace/space | 0.127mm/0.127mm (5/5mil) | 0.15mm (6mil) |
| Min via drill | 0.3mm | 0.3mm, larger where thermal/current demands it |
| Annular ring | per drill size | Standard JLCPCB minimums |
| Silkscreen on pads | avoid | Keep silkscreen clear of all pads |

---

## 9. Pre-routing checklist

Run this after placement, before you start drawing traces. Cheaper to fix here than after routing exists.

- [ ] Crystal ≥10mm from LM2596 and DRV8874, no switching trace routed near/under it
- [ ] I²C pair placement doesn't parallel any motor or switching trace
- [ ] R_IPROPI still at the STM32 end (per spec), and the IPROPI trace's planned route doesn't parallel motor traces
- [ ] IPROPI (and any other L1/L4 layer-swapped signal) verified not to cross the L3 zone boundary anywhere along its path (§5.3, §5.4)
- [ ] CAN pair placement doesn't parallel buck switching node or motor traces
- [ ] LM2596 SW–inductor–diode loop is as tight as physically possible
- [ ] AMS1117 (and any other zone-adjacent component near a switching loop) checked for loop-adjacency separately from zone placement (§4.4)
- [ ] VREF filter cap placement is directly at the DRV8874 VREF pin, not downstream of the divider
- [ ] DRV8874 VCC decoupling cap ground via is separate from the VM bulk cap ground return
- [ ] Star-point ground convergence identified as a single physical location near power input
- [ ] L3 plane split path sketched, confirmed not to cross under CAN pair, crystal, or I²C bus
- [ ] Test points reachable without obstruction from the motor connector or CAN header
- [ ] DRV8874 thermal pad via grid planned (4–9 vias, 0.3mm), JLCPCB via-in-pad handling confirmed
- [ ] VM/motor current path sized as a pour where possible, ≥40mil where routed as a trace
- [ ] Mounting holes (4× M3, corners) clear of copper/components per JLCPCB keep-out
- [ ] L3 VM/3.3V zone clearance set to 0.5mm in both zone properties and net class (§5.1)
- [ ] L1 and L4 flood-filled with GND, stitched to L2 every 5–10mm, checked for isolated copper islands (§5.2)

---

## 10. Cross-reference

This document assumes the following are already fixed by `CAN_Motor_Controller_Node_Spec.md` and does not re-derive them:
- Component values and part numbers (§3 of the spec)
- Decoupling cap counts and values (STM32, DRV8874, SN65HVD230, AS5600)
- 4-layer stackup decision and layer assignment
- Ground-return-path philosophy (§4 of the spec) — this document operationalizes it into concrete plane/routing rules
- Pin assignments (§5.2 of the spec)

If any of those change, revisit §3–§6 of this document for knock-on effects, particularly floorplan (§3) and plane split routing (§5).

---

*Last updated: alongside schematic capture completion — layout phase kickoff.*

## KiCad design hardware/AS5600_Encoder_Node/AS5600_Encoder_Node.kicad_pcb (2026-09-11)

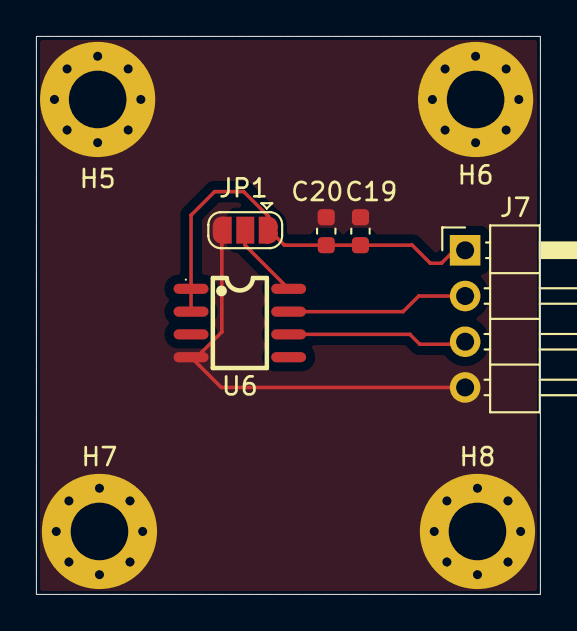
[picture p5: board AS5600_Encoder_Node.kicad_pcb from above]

Board: 2 copper layers, 28.0 x 31.0 mm, 9 parts (0 on the bottom side), 5 nets.

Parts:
C19: 100nF; C_0603_1608Metric
C20: 10uF; C_0603_1608Metric
H5, H6, H7, H8: MountingHole_Pad; MountingHole_3.2mm_M3_Pad_Via
J7: Conn_01x04; PinHeader_1x04_P2.54mm_Horizontal
JP1: SolderJumper_3_Open; SolderJumper-3_P1.3mm_Open_RoundedPad1.0x1.5mm
U6: AS5600-ASOT; SOIC-8_L5.0-W4.0-P1.27-LS6.0-BL

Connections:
+3V3: C19.1, C20.1, J7.1, JP1.1 (A), U6.1 (VDD5V), U6.2 (VDD3V3)
/AS5600_Encoder/DIR: JP1.2 (C), U6.8 (DIR)
/SCL: J7.2, U6.7 (SCL)
/SDA: J7.3, U6.6 (SDA)
GND: C19.2, C20.2, H5.1, H6.1, H7.1, H8.1, J7.4, JP1.3 (B), U6.4 (GND)

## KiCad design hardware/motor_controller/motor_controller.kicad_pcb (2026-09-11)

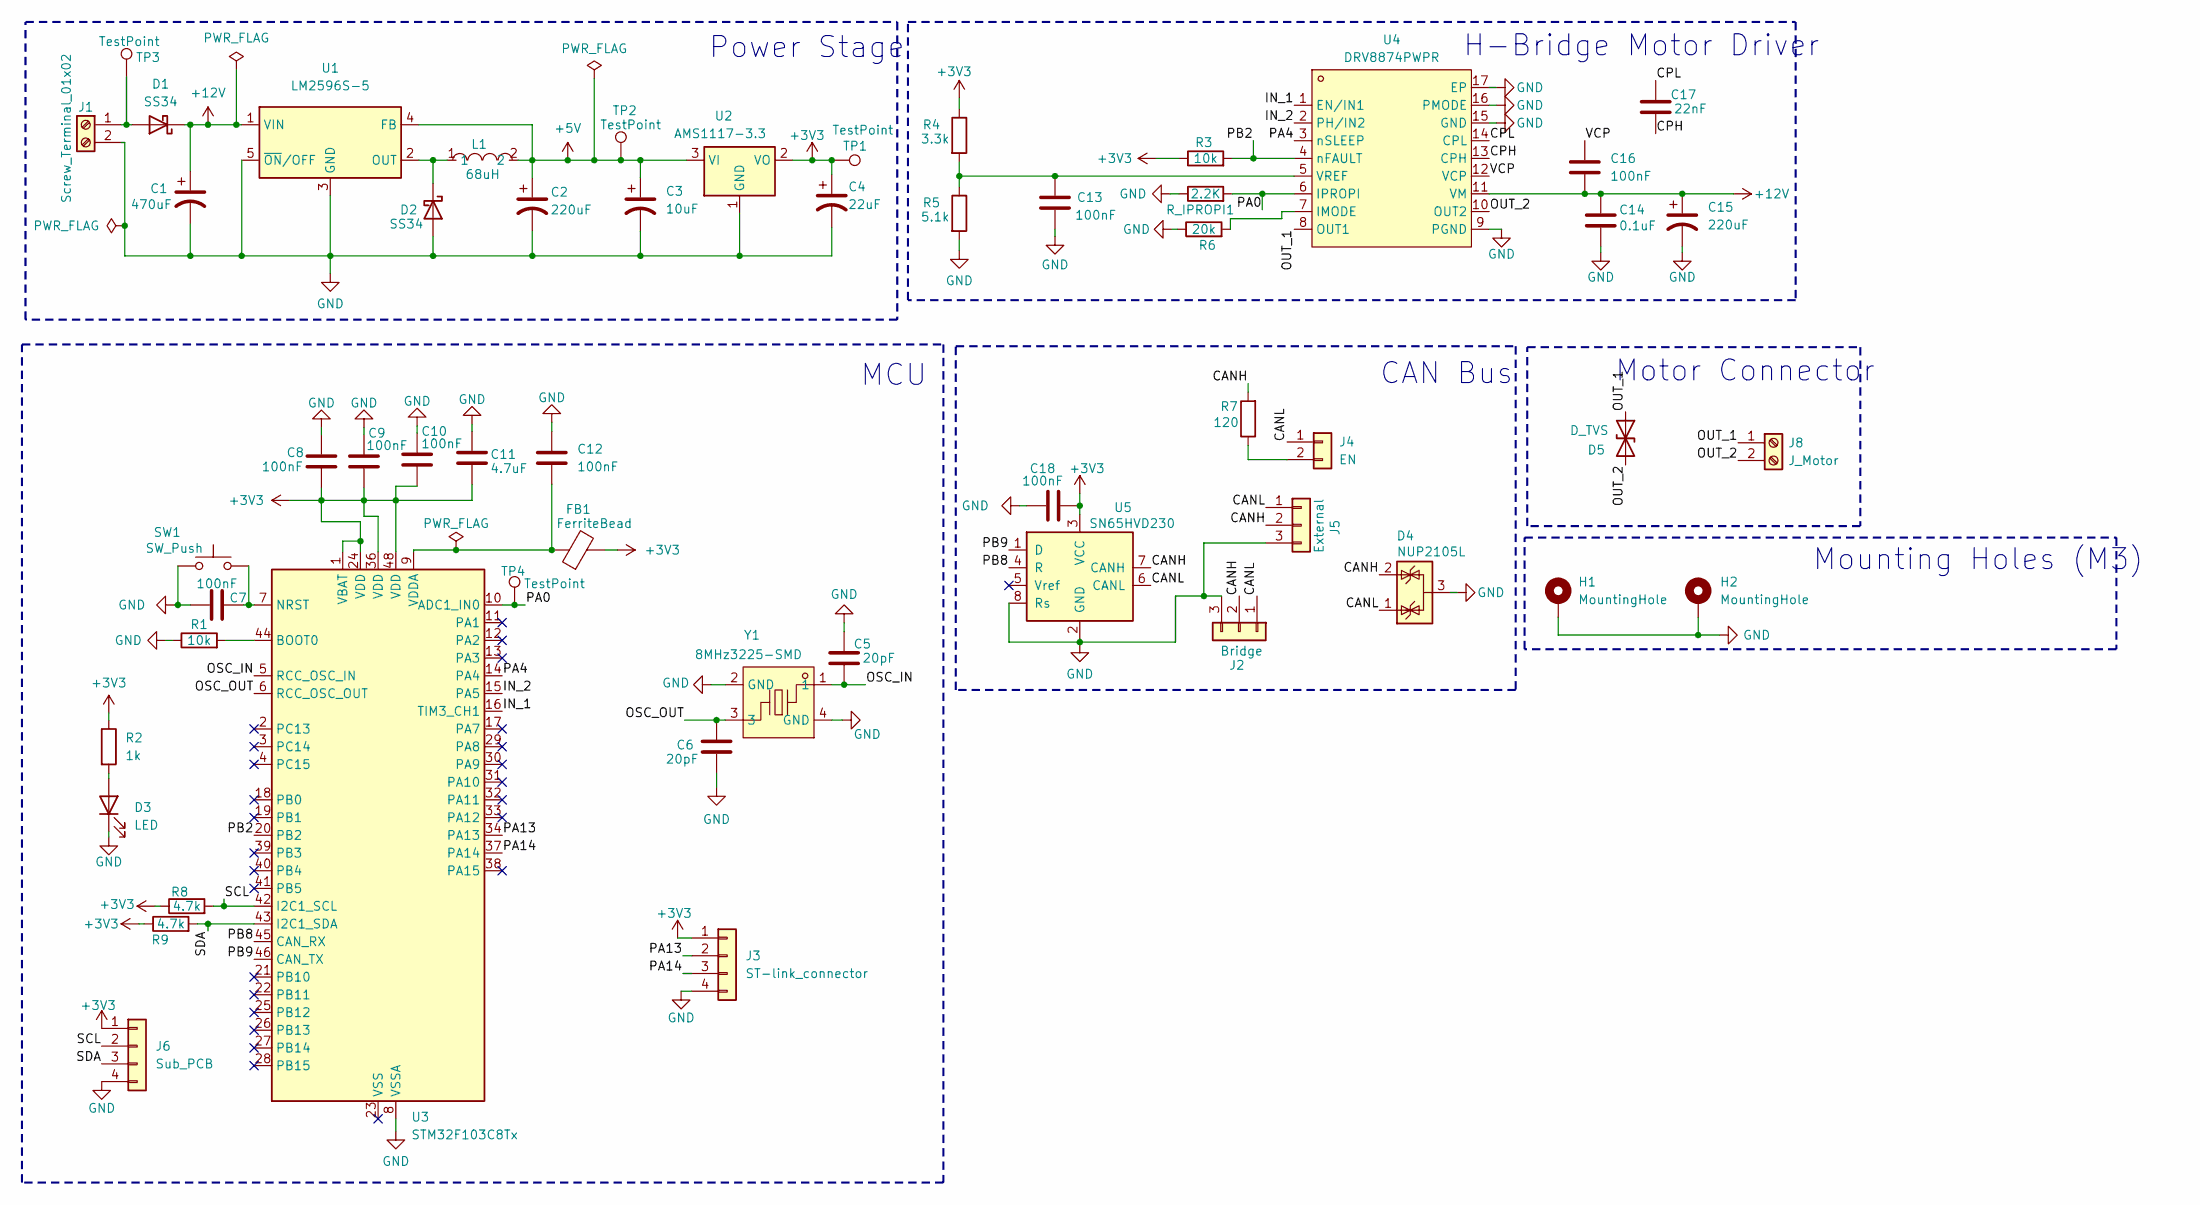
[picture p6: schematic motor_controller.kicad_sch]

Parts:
C1: 470uF; CP_Radial_D8.0mm_P3.50mm
C2, C15: 220uF; CP_Radial_D8.0mm_P3.50mm
C3: 10uF; CP_Radial_D8.0mm_P3.50mm
C4: 22uF; CP_Radial_D8.0mm_P3.50mm
C5, C6: 20pF; C_0603_1608Metric
C7, C8, C9, C10, C12, C13, C16, C18: 100nF; C_0603_1608Metric
C11: 4.7uF; C_0603_1608Metric
C14: 0.1uF; C_0603_1608Metric
C17: 22nF; C_0603_1608Metric
D1, D2: SS34; D_SMA
D3: LED; LED_0805_2012Metric
D4: NUP2105L; SOT-23
D5: D_TVS; D_SMA
FB1: FerriteBead; L_0805_2012Metric
H1, H2: MountingHole; MountingHole_3.2mm_M3_Pad_Via
J1: Screw_Terminal_01x02; TerminalBlock_Phoenix_MKDS-1,5-2-5.08_1x02_P5.08mm_Horizont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
J2: Bridge; JST_XH_S3B-XH-A_1x03_P2.50mm_Horizontal
J3: ST-link_connector; PinHeader_1x04_P2.54mm_Horizontal
J4: EN; PinHeader_1x02_P2.54mm_Vertical
J5: External; JST_XH_S3B-XH-A_1x03_P2.50mm_Horizontal
J6: Sub_PCB; PinHeader_1x04_P2.54mm_Horizontal
J8: J_Motor; TerminalBlock_Phoenix_MKDS-1,5-2-5.08_1x02_P5.08mm_Horizont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
L1: 68uH; IND-SMD_L12.3-W12.3_SMDRI127; MPN SMDRI127-680MT; LCSC Part C9907
R1, R3: 10k; R_0603_1608Metric
R2: 1k; R_0603_1608Metric
R4: 3.3k; R_0603_1608Metric
R5: 5.1k; R_0603_1608Metric
R6: 20k; R_0603_1608Metric
R7: 120; R_0603_1608Metric
R8, R9: 4.7k; R_0603_1608Metric
R_IPROPI1: 2.2K; R_0603_1608Metric
SW1: SW_Push; SW_SPST_PTS645Sx43SMTR92
TP1, TP2, TP3, TP4: TestPoint; TestPoint_Pad_D1.5mm
U1: LM2596S-5; TO-263-5_TabPin3
U2: AMS1117-3.3; SOT-223-3_TabPin2
U3: STM32F103C8Tx; LQFP-48_7x7mm_P0.5mm
U4: DRV8874PWPR; HTSSOP-16_L5.0-W4.4-P0.65-LS6.4-BL-EP; MPN DRV8874PWPR; LCSC Part C1855818
U5: SN65HVD230; SOIC-8_3.9x4.9mm_P1.27mm
Y1: 8MHz3225-SMD; CRYSTAL-SMD_4P-L3.2-W2.5-BL; MPN TAXM8M4RLBDDT2T; LCSC Part C720915

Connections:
+3V3: C4.1, C8.2, C9.2, C10.2, C11.2, C18.2, FB1.2, J3.1 (3V3), J6.1, R2.1, R3.1, R4.1, R8.1, R9.1, TP1.1, U2.2 (VO), U3.1 (VBAT), U3.24 (VDD), U3.36 (VDD), U3.48 (VDD), U5.3 (VCC)
+5V: C2.1, C3.1, L1.2, TP2.1, U1.4 (FB), U2.3 (VI)
+12V: C1.1, C14.1, C15.1, C16.1, D1.1 (K), U1.1 (VIN), U4.11 (VM)
/CANH: D4.2 (K), J2.2, J5.2, R7.2, U5.7 (CANH)
/CANL: D4.1 (K), J2.1, J4.1, J5.1, U5.6 (CANL)
/CPH: C17.2, U4.13 (CPH)
/CPL: C17.1, U4.14 (CPL)
/IN_1: U3.16 (TIM3_CH1), U4.1 (EN/IN1)
/IN_2: U3.15 (PA5), U4.2 (PH/IN2)
/OSC_IN: C5.2, U3.5 (RCC_OSC_IN), Y1.1
/OSC_OUT: C6.1, U3.6 (RCC_OSC_OUT), Y1.3
/OUT_1: D5.1 (A1), J8.1, U4.8 (OUT1)
/OUT_2: D5.2 (A2), J8.2, U4.10 (OUT2)
/PA0: R_IPROPI1.2, TP4.1, U3.10 (ADC1_IN0), U4.6 (IPROPI)
/PA4: U3.14 (PA4), U4.3 (nSLEEP)
/PA13: J3.2 (SWDIO), U3.34 (PA13)
/PA14: J3.3 (SWCLK), U3.37 (PA14)
/PB2: R3.2, U3.20 (PB2), U4.4 (nFAULT)
/PB8: U3.45 (CAN_RX), U5.4 (R)
/PB9: U3.46 (CAN_TX), U5.1 (D)
/SCL: J6.2, R8.2, U3.42 (I2C1_SCL)
/SDA: J6.3, R9.2, U3.43 (I2C1_SDA)
/VCP: C16.2, U4.12 (VCP)
GND: C1.2, C2.2, C3.2, C4.2, C5.1, C6.2, C7.1, C8.1, C9.1, C10.1, C11.1, C12.1, C13.2, C14.2, C15.2, C18.1, D2.2 (A), D3.1 (K), D4.3 (A), H1.1, H2.1, J1.2, J2.3, J3.4 (GND), J5.3, J6.4, R1.1, R5.2, R6.1, R_IPROPI1.1, SW1.1, U1.3 (GND), U1.5 (~ON/OFF), U2.1 (GND), U3.8 (VSSA), U4.9 (PGND), U4.15 (GND), U4.16 (PMODE), U4.17 (EP), U5.2 (GND), U5.8 (Rs), Y1.2 (GND), Y1.4 (GND)
unnamed: D1.2 (A), J1.1, TP3.1
unnamed: D2.1 (K), L1.1, U1.2 (OUT)
unnamed: D3.2 (A), R2.2
unnamed: J4.2, R7.1
unnamed: R1.2, U3.44 (BOOT0)
unnamed: C7.2, SW1.2, U3.7 (NRST)
unnamed: C12.2, FB1.1, U3.9 (VDDA)
unnamed: R6.2, U4.7 (IMODE)
unnamed: C13.1, R4.2, R5.1, U4.5 (VREF)

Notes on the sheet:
CAN Bus
Motor Connector
Power Stage
H-Bridge Motor Driver
MCU
Mounting Holes (M3)

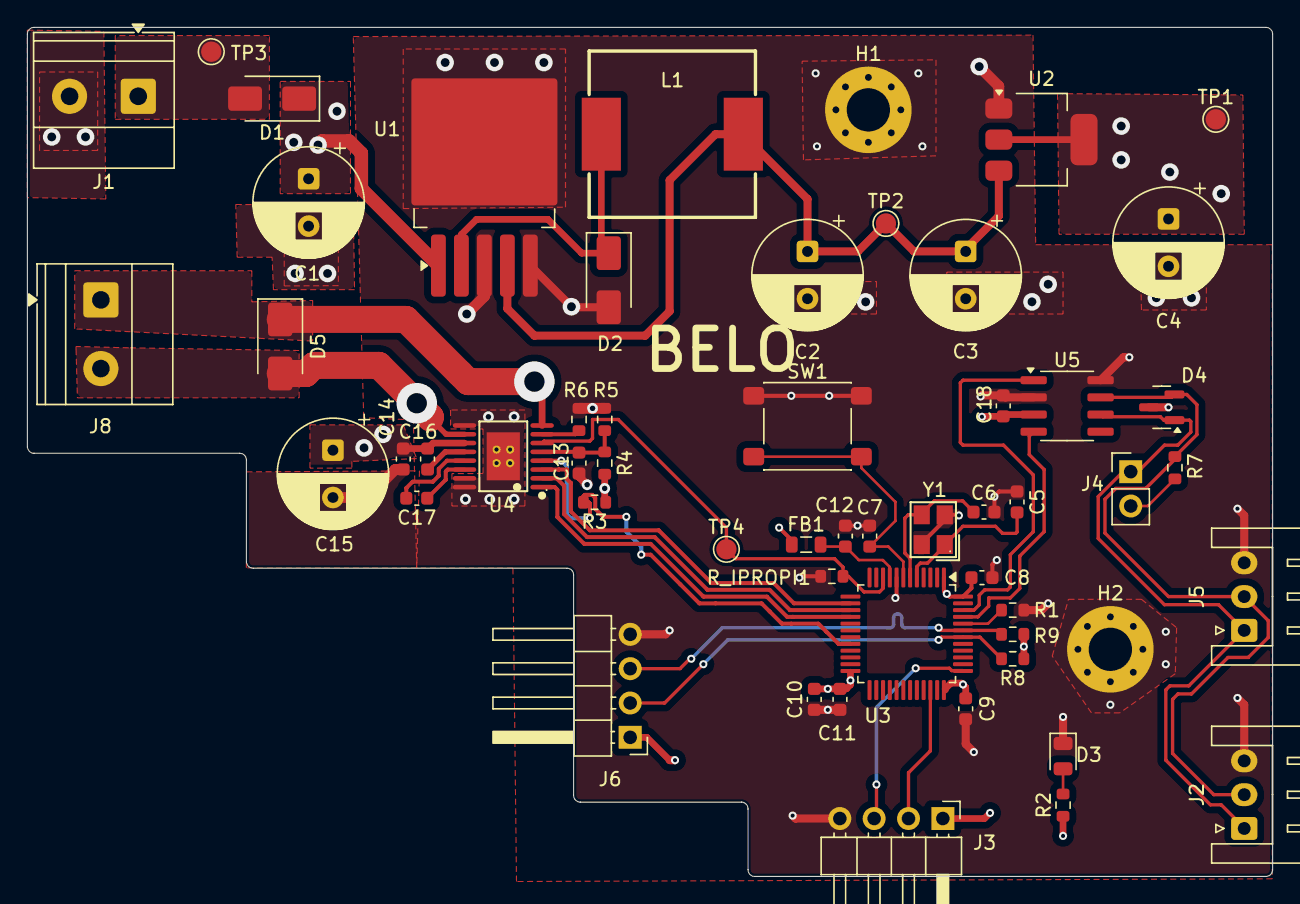
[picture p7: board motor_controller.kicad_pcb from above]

Board: 4 copper layers, 92.1 x 62.8 mm, 55 parts (0 on the bottom side), 33 nets.

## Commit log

2026-09-11 Initial commit: CAN motor controller node + AS5600 encoder sub-PCB
    Two KiCad hardware projects:
    - hardware/motor_controller: main CAN-connected closed-loop DC motor
    controller node (STM32F103, DRV8874 H-bridge, SN65HVD230 CAN
    transceiver, two-stage power supply)
    - hardware/AS5600_Encoder_Node: small sub-PCB carrying the bare AS5600
    magnetic angle sensor, linked to the main board over JST-SH
    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
    [AS5600_Encoder_Node-B_Cu.gbr, AS5600_Encoder_Node-B_Mask.gbr, AS5600_Encoder_Node-B_Paste.gbr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]
2026-09-11 Add PCB layout and 3D render images for both boards
    Adds hardware_design.png (3D render) and PCB_design.png (layout
    screenshot) for motor_controller and AS5600_Encoder_Node, and surfaces
    them in a Gallery section in README.md so they render on the repo's
    front page.
    Claude-Session: https://claude.ai/code/session_01F2qMBfwDCjQiyZghioP5Ni
